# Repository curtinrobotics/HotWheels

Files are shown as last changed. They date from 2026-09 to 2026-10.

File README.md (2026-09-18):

# Hot_Wheels_RC

Welcome to the **Hot Wheels** project for Curtin Robotics club (CRoC)

This repository contains Arduino, ESP32, C++ codebases, hardware design, mechanical/electrical schematics.

---

## Project Structure

```text
Hot_Wheels_RC/
├── archive/                    -> archival assets, may be still relevant
├── docs/                       -> Documentation for the project
├── hardware_design/            -> CAD and schematic files for the hardware components
│   ├── Hot_Wheels_3d_model/    -> 3D model exported files (e.g., .stl, .step) for manufacturing and prototyping
├── Hot_Wheels_arduino_firmware/ -> Arduino firmware source code
```

## CAD - Onshape

This project uses Onshape for its CAD (computer-aided design) work. It is publicly available here: <https://cad.onshape.com/documents/5e98e5633ee093c54380ece6/w/86f2519afc7872e03f376baa/e/f928c5beb2e31589149b2275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>

## Collaboration Guidelines

To ensure smooth teamwork:

- **Commit, pull, and push frequently** to keep everyone on the same page.
- **Create a branch** for any experimental or testing-specific changes. Once stable, we can discuss merging them into the main codebase.
- If you have questions, feel free to reach out to Aron or Joshan

---

Contributors:

- **Shea, Aron**

---

## Nix Flake Quickstart (recommended)

This repo ships a `flake.nix` that pins the full Arduino toolchain (via Nix) and pins the _two ESP32 package indexes_ needed for this project:

- Espressif Arduino-ESP32 index
- Bluepad32 Arduino-ESP32 fork index

That means a new contributor can build on macOS/Linux without installing Arduino IDE, platform packages, or toolchains manually.

### Installing Nix

Nix is required to use this development environment. Install it using either the [official Nix installation guide](https://nixos.org/download/) or the [Determinate Nix Installer](https://manual.determinate.systems/installation/). The Determinate installer enables flakes by default.

### 1) Enter the dev shell

```sh
nix develop -c $SHELL
```

### 2) Confirm the ESP32 + Bluepad32 core is present

```sh
arduino-cli core list
```

You should see `esp32-bluepad32:esp32` installed.

### 3) Build the firmware

The target board for this project is **ESP32 Dev Module** from the Bluepad32 core:

- FQBN: `esp32-bluepad32:esp32:esp32`

#### Build with the flake

```sh
nix build
```

The generated firmware files are available under `./result/`. The `result` symlink is ignored by Git.

#### Build with the Nix-provided Arduino CLI

Run this from the development shell:

```sh
arduino-cli compile \
	--fqbn esp32-bluepad32:esp32:esp32 \
	Hot_Wheels_arduino_firmware/Hot_Wheels_arduino_firmware.ino
```

### 4) Flash and monitor the board

Enter the development shell if it is not already active, then identify the connected board:

```sh
arduino-cli board list
```

Set `PORT` to the port reported by the previous command. macOS ports commonly start with `/dev/cu.`, while Linux ports commonly start with `/dev/ttyUSB` or `/dev/ttyACM`.

#### Flash and monitor with the flake

```sh
PORT="<serial-port>"

nix run .#flash -- "$PORT"
nix run .#monitor -- "$PORT"
```

#### Flash and monitor with the Nix-provided Arduino CLI

Run this from the development shell. The commands use the firmware files generated by `nix build`:

```sh
arduino-cli upload \
	--input-dir result \
	--port "$PORT" \
	--fqbn esp32-bluepad32:esp32:esp32 \
	--verify

arduino-cli monitor \
	--port "$PORT" \
	--config baudrate=115200
```

If the board does not enter upload mode automatically, hold its **BOOT** button while starting the upload, then release it when the upload begins.

### Development checks

The flake provides repository-wide maintenance and checks:

```sh
# Fix and validate the repository
nix fmt
# or, from the development shell
fmt

# Check the repository
nix flake check
# or, from the development shell
chk

# Run an individual firmware check
nix run .#firmware-check
nix run .#flash -- "$PORT"
nix run .#monitor -- "$PORT"
```

The development shell also installs repository checks as pre-commit hooks.

### VS Code workflow

The repository includes editor settings and tasks in `.vscode/`. Extension choices are intentionally left to each contributor. In the command palette, use **Tasks → Run Task** to run the Nix build, formatter, flake check, board listing, flash, and serial monitor commands. The flash task builds the firmware first and then prompts for the board's serial port. If your editor does not automatically load `.envrc`, run `nix develop` manually.

### Notes on Bluepad32 library

The sketch includes `#include <Bluepad32.h>`. In this setup, the header is provided by the **esp32-bluepad32 platform package** (it bundles the library), so `arduino-cli lib list` may still show “No libraries installed” even though the include resolves.

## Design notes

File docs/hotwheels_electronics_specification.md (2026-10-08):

# Hot Wheels RC Electronics and PCB Specification

## Document control

| Field | Value |
| --- | --- |
| Status | Draft requirements capture |
| Target | 1:43-scale car, PCB Rev A  |
| Baseline controller | ESP32-WROOM-32UE-N8 |
| Last updated | 24 September 2026 |

## Purpose

This document records the intended features, design constraints and unresolved decisions for the car's electronics and PCB. It is the working reference for the schematic, PCB layout, firmware interfaces and later verification.

The document describes what the design needs to achieve. Component choices, dimensions and pin assignments can change as measurements and prototypes provide better information.

The terms below indicate how settled an item is:

- **Must** means it is required for the first board to be accepted.
- **Should** means it is strongly preferred unless a documented trade-off prevents it.
- **May** means it is optional or intended for a later revision.
- **TBD** means a decision or measurement is still required.

## Product intent

The vehicle is a 1:43-scale RC car intended to combine low-latency driving with telemetry and interactive track features. The PCB will contain the main electronics and form the structural centre of the chassis.

The design should remain modular. The body-mounted lights, forward distance sensor, floor colour sensor, wheel-speed sensor and motor thermistor should connect with cables so their positions can be adjusted and parts can be replaced. Front and rear mechanical sections should attach to the PCB and remain replaceable.

## Confirmed design direction

| Area | Decision |
| --- | --- |
| Vehicle scale | 1:43 |
| Main controller | ESP32-WROOM-32UE-N8 castellated module with 8 MB flash |
| Battery | 2S 600 mAh 20C LiPo, approximately 49 × 18 × 15 mm |
| Brushed motor driver | DRV8833 dual H-bridge |
| Motor-current sensing | Onboard sensing of both DRV8833 bridge currents |
| Battery-voltage sensing | Protected onboard divider connected to an ADC1 input |
| Inertial sensing | Onboard BMI160 three-axis accelerometer and three-axis gyroscope |
| Steering supply | Regulated 6 V |
| Steering connection | Three-pin connector; keyed preferred, with a controlled unkeyed DuPont exception |
| Forward ranging | Cable-mounted TOF400C module using VL53L1X |
| Floor colour sensing | Cable-mounted AS7341 V2 module |
| Motor temperature | Cable-mounted MF52B 10 kΩ, B3750 NTC thermistor |
| Initial wheel-speed sensor | Cable-mounted 49E Hall sensor and wheel magnet |
| Lighting | Dimmable underglow, headlights and taillights |
| Underglow | Top-mounted WS2812-family LEDs with a reflector or 3D-printed light redirector |
| Audio | Buzzer for interaction, warnings and find-me operation |
| Assembly | Reflowed parts on the top side only, suitable for hotplate assembly |
| Chassis | PCB forms the structural centre, with generic front and rear extensions |
| PCB envelope | 88 mm long, 44 mm maximum width and 12 mm front/rear arms |
| PCB thickness | 1.6 mm and 1.8 mm candidates; final choice after stiffness and cost comparison |
| Fasteners | M2 thin-head screws inserted from underneath |
| ESP32 mounting | Direct castellated-module footprint |
| Base-station radio | Direct peer-to-peer control and telemetry without joining the car's access point |

The ESP32-WROOM-32UE-N8 is the Rev A baseline. It replaces the earlier D1 Mini and ESP32-S module directions. The N8 variant provides 8 MB of flash for firmware and OTA update headroom, while the external-antenna variant uses an external antenna connection rather than relying on a selectable PCB-antenna/U.FL path.

## System overview

The 2S battery will feed the main input protection and power switch. Raw battery voltage will supply the DRV8833 and optional external ESC power connection. A dedicated regulator will produce 6 V for the steering servo. A dedicated 3.3 V logic supply will power the ESP32-WROOM-32UE-N8 and compatible sensors.

The ESP32 will handle motor and servo control, lighting, audio, sensor acquisition, Bluetooth controller support, ESP-NOW communication and telemetry. Motor-current, battery-voltage and inertial measurements will also support diagnostics, data logging and optional driver-assist functions.

The 6 V servo rail must not be connected directly to the ESP32 module's 3.3 V supply.

## Main functional requirements

- The PCB must operate as the electronic controller and structural centre of the 1:43-scale car.
- The car must provide proportional steering and proportional forward and reverse motor control.
- Propulsion must stop after communication loss, controller disconnection, ESP32 reset or a serious motor-driver fault.
- The body shell must be removable without desoldering lights or sensors.
- External sensors should be replaceable and positionable through keyed cable connections.
- The car must send live telemetry while being driven.
- Track-marker and power-up features must not make safe manual driving dependent on the central server.
- The board should provide accessible test points for power rails and critical signals.
- The PCB must measure battery voltage, motor current, acceleration and angular velocity.
- Driver assists must be independently configurable and must fail back to normal manual control when their inputs are invalid.

## Wireless control and telemetry

### Operating modes

| Mode | Control | Telemetry | Intended use |
| --- | --- | --- | --- |
| Base-station mode | Direct ESP-NOW or equivalent peer-to-peer link | Bidirectional over the same link | Primary Rev A mode |
| Direct-controller mode | Bluetooth Classic through Bluepad32 | Limited, stored locally or provided through a separately tested link | Standalone and fallback use |
| Development mode | External USB-C-to-UART programming adapter | Serial logging through the same adapter | Bench testing |

### Radio requirements

- The base station must not connect to the car's access point for control or telemetry, so the base station can retain its normal internet connection.
- ESP-NOW unicast between known peers is the first implementation choice for Rev A.
- The base station should pass telemetry to a computer over USB so the computer keeps its normal internet connection.
- The car must stop if valid control packets are not received within a defined timeout.
- Telemetry loss must not interrupt otherwise valid control.
- Packets must include a car identity, packet type, sequence number, command age and fault state.
- Each car must accept driving commands only from its paired base station during multi-car events.
- The radio channel must be documented and configurable.
- Bluetooth Classic and ESP-NOW share the ESP32 radio. Simultaneous operation must be measured before it is considered supported.

### Initial performance targets

| Measurement | Initial target |
| --- | ---: |
| Control update rate | At least 100 Hz |
| Typical command latency | 20 ms or less |
| Failsafe stop after lost control | 100 ms or less |
| Basic telemetry rate | At least 20 Hz |
| Packet-loss measurement | Continuous, using sequence numbers |

These values are starting targets for testing rather than fixed production limits.

## Battery and power

The selected battery is a 2S 600 mAh 20C LiPo measuring approximately 49 × 18 × 15 mm. Space must also be allowed for the cable, connector, bend radius and removal path.

A 2S LiPo is nominally 7.4 V and reaches 8.4 V when fully charged. All parts connected to the battery rail must tolerate the fully charged voltage.

### Planned power rails

| Rail | Source | Main loads |
| --- | --- | --- |
| VBAT | 2S LiPo | DRV8833 and optional ESC power pads |
| 6V_SERVO | 6 V MiniBuck module from VBAT | Steering servo |
| 3V3 | 3.3 V MiniBuck module from VBAT | ESP32-WROOM-32UE-N8 and compatible sensors |
| GND | Common return | All loads |

The current schematic uses separate fixed-output MiniBuck modules for the 6 V servo rail and 3.3 V logic rail. Any remaining 5 V loads must have an explicitly defined supply before schematic release; a 5 V rail is not assumed simply because some peripherals can use it.

### Power requirements

- The board must operate across the expected 2S battery range and tolerate 8.4 V at full charge.
- Battery polarity must be keyed and clearly marked.
- The battery connector must not mate with the motor or sensor connectors.
- The switch, protection, copper and connectors must be sized from measured system current.
- Battery voltage must be measurable through a protected divider connected to ADC1.
- Firmware must provide configurable low-battery warning and shutdown thresholds.
- Motor and servo current transients must not reset the ESP32 or corrupt sensor readings.
- Local ceramic and bulk decoupling must be provided at regulators, the motor driver, the servo connection and the ESP32 supply.
- The external USB-UART programming interface must not back-power the battery or 3.3 V rail through an unsafe path.
- Reverse-polarity, short-circuit and input transient protection must be reviewed before schematic release.
- The battery-voltage measurement circuit must tolerate at least 8.4 V plus component tolerances without exceeding the ESP32 ADC input range.
- Battery telemetry must distinguish sustained low voltage from short motor- or servo-induced voltage sag.

Rev A presently omits an inline fuse, MOSFET reverse-polarity protection and input TVS. This does not protect the PCB against reversed battery insertion or a hard short. Battery connector polarity must be checked before power-up; the supply path and wiring require review again after measuring motor and servo current. See the [schematic review](reva_schematic_review.md) for remaining acceptance gates.

The battery's 20C label implies an advertised current capability of 12 A. It does not mean the PCB needs to carry 12 A, but it means the battery may deliver destructive current into a fault. Actual motor and servo currents must be measured.

### Battery-voltage monitoring

The protected voltage divider will use an ADC1 input so it remains available while Wi-Fi is active. The input should include suitable filtering and protection, while the divider resistance must avoid unnecessary battery drain and remain compatible with the ADC input requirements.

Firmware will calibrate divider ratio and ADC error against a trusted meter. It should report raw and filtered battery voltage, detect rapid sag under load, and provide configurable warning, power-reduction and shutdown thresholds.

## Brushed motor system

The PCB will include a DRV8833 dual H-bridge.

It should support both:

- one brushed motor with the two bridges connected in parallel for additional current;
- two brushed motors using one independent bridge per motor.

The parallel and independent arrangements may use solder links, zero-ohm resistors or separate assembly variants. The selected arrangement must be obvious, and firmware must not drive the bridges independently while their outputs are tied together.

- Motor running and stall current must be measured before the driver package and copper layout are finalised.
- The DRV8833 must have hardware-defined safe input and nSLEEP states while the ESP32 is resetting.
- The nFAULT output should be routed to the ESP32 if a suitable pin is available.
- Motor connectors and wiring must be rated for measured stall current.
- Motor and battery connectors must be physically incompatible.
- Motor suppression and layout must limit brush noise and inductive transients.
- Each motor configuration must be tested separately for current, temperature, reversing and fault behaviour.
- The PCB must measure the current through both DRV8833 bridges.
- In dual-motor mode, bridge A and bridge B current must be available separately; in parallel-bridge mode, firmware must report their combined motor current.
- The current-measurement range must include normal running, acceleration and stall current with suitable transient margin.
- Current-sense failure or saturation must not be interpreted as a safe zero-current condition.
- Current warnings and software intervention thresholds must be configurable, but firmware must not replace the driver's hardware current regulation and thermal protection.

The current schematic uses the DRV8833PW package. Texas Instruments gives the PW package a lower continuous RMS rating than the thermally enhanced PWP and RTY versions. The final package choice therefore depends on measured current and thermal testing.

### Motor-current measurement

The DRV8833 AISEN and BISEN inputs support low-side sense resistors for bridge current regulation. Rev A should measure both sense paths so one circuit supports either two independent motors or one motor driven by parallel bridges.

The measurement circuitry must not load the sense nodes or change the hardware current-trip point. The schematic should provide Kelvin-connected sensing, appropriate gain and PWM-noise filtering, and test points for comparing the reported current with bench instruments. Current values must be calibrated and included in live telemetry, fault logging and stall detection.

## Optional brushless system

The PCB should retain the brushed driver while also providing an interface for a purchased external brushless ESC.

- The board should provide an external ESC signal and ground connection.
- The initial signal format is expected to be servo-style PWM, subject to the selected ESC.
- Any ESC-provided BEC output must be isolated by default.
- The ESC connection should be removable without affecting steering or sensors.

The interface may use labelled solder pads or a keyed connector, depending on available PCB area.

## Steering

The steering servo may use a 2.54 mm DuPont connector or another keyed three-pin connector. If an unkeyed DuPont connector is used, the pin order must place regulated 6 V on the centre pin, with signal and ground on the outer pins. This keeps the supply contact in the centre if the plug is reversed, but it does not eliminate signal/ground reversal risk. The unkeyed 2.54 mm DuPont connector is the only permitted unkeyed connector for Rev A.

- The 6 V regulator and connector must be sized for measured servo stall current.
- Steering direction, center trim, pulse range and endpoints must be configurable via software.
- Startup and communication-loss behaviour must not drive the linkage beyond its safe range.

## Sensors

### Sensor summary

In this table, “Onboard” means mounted directly on the PCB.

| Function | Device | Interface | Mounting |
| --- | --- | --- | --- |
| Wheel speed | 49E Hall sensor and wheel magnet | Analog | Adjustable cable-mounted sensor |
| Motor temperature | MF52B 10 kΩ, B3750 NTC | Resistive divider to ADC1 | Attached to the motor |
| Motor current | DRV8833 bridge sense resistors and measurement circuitry | Analog or dedicated current IC | Onboard |
| Forward distance | TOF400C with VL53L1X | I2C | Forward-facing cable-mounted module |
| Floor colour | AS7341 V2 | I2C (sensor + onboard LED control) | Downward-facing cable-mounted module |
| Battery voltage | Onboard divider | Analog | Onboard |
| Acceleration and angular velocity | BMI160 six-axis IMU | I2C or SPI, with data-ready interrupt preferred | Top side of the main PCB near its centre |

### Wheel speed

The 49E sensor will connect through a three-pin connector carrying 3.3 V, ground and signal. Its position must be adjustable relative to a magnet recessed into a wheel.

A 49E is a linear Hall sensor rather than a digital switch. The prototype can detect each magnet pass using an analog threshold. A digital Hall switch may replace it later if it gives cleaner pulse timing.

Wheel circumference and magnets per revolution must be configurable. One magnet is acceptable for the first prototype, although low-speed resolution and missed pulses need testing.

### Motor temperature

The MF52B 10 kΩ, B3750 thermistor will attach to the motor and connect through a two-pin cable. The PCB will contain the other resistor in the divider, and the measurement must use ADC1.

Firmware should support calibration, a warning threshold, reduced-power operation and a shutdown threshold. Open and shorted sensor faults should not be interpreted as valid temperatures.

### Forward ranging

The TOF400C/VL53L1X module will be positioned independently from the main PCB. Its connector should provide power, ground, SDA, SCL and, where exposed by the selected module, shutdown and interrupt.

The sensor may provide obstacle warnings, emergency intervention and distance-to-car information. It must not be treated as the only collision-safety mechanism.

Ranging must not block the steering and motor-control loop. Invalid or timed-out readings must not be interpreted as a clear path.

The VL53L1X field of view, timing budget, ambient-light performance and mounting angle need testing on the actual car. A fast short-range mode is likely more useful than its slow maximum-range setting.

### Floor colour and track markers

The AS7341 V2 module will face the track and connect through a cable. It will not be soldered to the underside of the main PCB.

The sensor needs controlled floor clearance and protection from striking the track. A small shroud should reduce interference from underglow, headlights, sunlight and body reflections.

Track markers will use unique three-colour sequences. They may identify track sections, report progress and request random power-ups from a central server.

Marker events should include:

- marker identity;
- local timestamp;
- detection confidence;
- duplicate suppression state.

Marker width, spacing, vehicle speed, illumination and sensor sample rate must be tested together so each colour bar produces enough readings.

### Inertial measurement and driver assists

The PCB will include a BMI160 containing a three-axis accelerometer and three-axis gyroscope. It should be mounted rigidly on the top side near the vehicle centre where practical, with its X and Y axes aligned to the vehicle axes. The sensor orientation and positive-axis directions must be marked on the silkscreen and recorded in firmware.

- The BMI160 supply must be locally decoupled and its placement must minimise interference from the motor driver, regulators, buzzer and high-current traces.
- A data-ready interrupt should be routed to the ESP32; the second interrupt should be routed if GPIO availability permits.
- The initial control-oriented sample-rate target is at least 200 Hz, subject to bus loading and measured noise.
- Firmware must calibrate accelerometer and gyroscope offsets and compensate for the documented PCB mounting orientation.
- Raw acceleration, angular velocity, calibration state and sensor-health information must be available to telemetry and logging.
- Invalid, stale or uncalibrated IMU data must disable dependent assists without interrupting manual steering or throttle control.

The first intended driver-assist experiment is bounded automatic counter-steer during a detected drift. It may use yaw rate, lateral acceleration, wheel speed, driver steering and throttle state. The assist must be disabled by default until calibrated, must limit its steering contribution, must allow immediate driver override and must never command steering beyond the tested mechanical endpoints.

### Shared I2C bus

The BMI160 now uses the existing 3.3 V I2C bus with address 0x68 (CSB tied high, SDO tied low), preserving its INT1 connection on GPIO16. This frees output-capable GPIOs for lighting and audio without adding an I/O expander. The VL53L1X, AS7341, ADS1115 and BMI160 share SDA/GPIO21 and SCL/GPIO22. Check actual breakout-board voltage tolerances, addresses, bus capacitance and onboard pull-ups before power-up; the main PCB has one 4.7 kΩ pair.

If their connectors are physically compatible, they must use the same safe power, ground, SDA and SCL ordering. Swapping two I2C modules should not damage either one.

The design should use one intentional set of bus pull-ups or configurable pull-ups. Pull-ups already fitted to the modules must be included in the calculation.

## Lighting and audio

### Lighting

| Function | Device | Interface | Mounting |
| --- | --- | --- | --- |
| Underglow  | WS2812B-2020-V6 (2 LEDs) | Digital (GPIO2, 3.3 V) | Top side of the main PCB |
| Headlights | White THT LEDs | Digital (transistor, PWM) | Removable body shell harness |
| Taillights | Red THT LEDs | Digital (transistor, PWM) | Removable body shell harness |

The underglow will use normal top-mounted WS2812-family LEDs. A reflective surface or simple 3D-printed light guide will redirect some light toward the ground. Uniform illumination is not required for Rev A.

The two 2020-size WS2812B-V6 pixels are powered directly from 3.3 V. The selected V6 variant must be purchased, not substituted with older 3.5 V-minimum versions. Worldsemi documents an integrated bypass capacitor on the 2020 version, so no separate per-pixel capacitors are placed. GPIO2 is a boot-strapping pin and the final assembly must verify that the data input does not force a high level during reset. The number and placement of pixels can be revised after optical and power-budget testing. See [Worldsemi WS2812B-2020-V6](https://www.world-semi.com/products/ws2812b-2020-v6.html).

The WS2812 power supply, data-line conditioning and bypass capacitors must follow the exact LED variant's requirements. If a 3.3 V ESP32 signal does not reliably meet the input-high requirement of LEDs powered from 5 V, a logic-level buffer should be included.

The body shell uses a keyed 5-pin JST ZH harness: 1 = +6 V, 2 = left headlight cathode, 3 = right headlight cathode, 4 = left taillight cathode, 5 = right taillight cathode. The LED anodes share +6 V. Each cathode returns through its own 470 Ω SMT resistor to one of two AO3400A low-side PWM switches (GPIO17 headlights, GPIO18 taillights). Each gate has a 100 kΩ pulldown to GND to hold the body lights off at reset. These resistors suit a provisional single white LED on each side of the front and a single red LED on each side of the rear; actual LED forward voltage, brightness and resistor power must be measured and the resistor values revised as necessary.

Lighting power and switching noise must not disturb the colour sensor, radio or ESP32 supply.

### Buzzer

Rev A uses a Same Sky (CUI Devices) CPT-9019S-SMT-TR passive 4 kHz SMD piezo, connected between GPIO19 and GND. Its specified current is 5 mA at 3 Vp-p, 4 kHz, so it is driven directly from the GPIO with no transistor. Validate the 3.3 V output waveform and pin loading during prototype bring-up. Sound playback must be nonblocking and must not interfere with motor failsafe handling.

## ESP32 and GPIO planning

Rev A uses the ESP32-WROOM-32UE-N8 directly on the PCB. The castellated module removes the D1 Mini carrier board, socket headers and onboard USB connector, reducing both footprint and stack height. The N8 variant is required so the design has 8 MB of flash for firmware growth and OTA update partitions.

The ESP32-WROOM-32UE-N8 uses an external antenna connector. The antenna, coax and connector require a protected mechanical route and clearance from the battery, motor, wiring, fasteners and noisy or grounded structures. The RF layout and antenna placement must follow Espressif's module guidance. An external antenna must be connected before the ESP32 is powered.

### Programming interface

USB-to-UART conversion remains off-board. Rev A should expose a compact programming/debug connector carrying the UART signals, ground and any required boot/reset control so a reusable external USB-C-to-UART adapter can program and log the car without dedicating PCB area and height to a USB connector and bridge IC.

The external programmer must not feed an unsafe voltage into the 3.3 V rail or back-power the battery path. Boot and enable circuitry must leave the module in a valid reset state when no programmer is attached.

### Rev A schematic GPIO allocation

| GPIO | Function | Notes |
| ---: | --- | --- |
| 0 | Programming BOOT | Keep boot/reset interface accessible |
| 1 / 3 | UART TX / RX | Off-board USB-UART programmer |
| 2 | WS2812B-2020-V6 data | Strapping pin: verify boot-time DIN loading |
| 4 / 5 | VL53L1X INT / XSHUT | Internal pull-up for interrupt; output-capable shutdown |
| 13 | DRV8833 nSLEEP | Hardware-defined safe startup state |
| 14 / 25 / 26 / 27 | DRV8833 bridge inputs | Four outputs support two bridges |
| 15 | Optional brushless ESC PWM | Strapping pin: verify ESC input at reset |
| 16 | BMI160 INT1 | Keep available for sensor event interrupt |
| 17 / 18 | Headlight / taillight PWM | Two AO3400A low-side driver gates |
| 19 | Passive piezo drive | Direct 3.3 V, current verified against piezo datasheet |
| 21 / 22 | I2C SDA / SCL | BMI160, ADS1115, VL53L1X, AS7341 |
| 23 | Spare | Unused output-capable GPIO |
| 32 | Analog Hall wheel-speed sensor | ADC1 |
| 33 | Steering servo PWM | 6 V servo supply is separate |
| 34 / 35 | Spare input-only | No internal pull-ups |
| 36 / 39 | Battery voltage / motor thermistor | ADC1 |
| 12 | Spare, strapping | Leave unconnected until reset-state constraints are checked |

The ADS1115 samples both motor-current sense channels without consuming ESP32 ADC pins. The battery divider, thermistor and Hall sensor remain on ADC1 so sensing can operate while Wi-Fi is active.

The BMI160 I2C allocation replaces an earlier SPI allocation. I2C timing and shared-bus behavior with the other sensors require firmware validation under combined operation. No I/O expander is included.

Boot-strapping pins must not be connected to circuits that force an invalid boot state. Sensor and lighting input states need checking during reset and programming.

## Connectors

Connectors should be easy to acquire and use, while preventing incorrect insertion, orientation or location that could cause over-voltage, reversed polarity or a short circuit.

### Connector rules

- Every removable connector must be keyed or mechanically unique, except for the steering servo, which may use the controlled unkeyed DuPont arrangement described above.
- Battery and motor connectors must never be mutually compatible.
- Incompatible voltages should use different families, pitches or pin counts.
- If two connectors can mate, their power and ground positions must be compatible.
- Pin one, voltage and function should be marked on the top silkscreen.
- Cable exits must avoid wheels, steering, gears, motor shafts and sharp PCB edges.
- High-current connectors must be selected using measured load current and wire size.

### Candidate connector plan

| Function | Pins | Candidate approach | Important constraint |
| --- | -----: | --- | --- |
| Battery | 2 | Match the pack (JST-PH) or use a dedicated keyed power family | Must be unique on the car |
| Brushed motor 1 | 2 | Different family from battery or direct solder pads | Stall current |
| Brushed motor 2 | 2 | Same safe motor pinout as motor 1 | Optional connection |
| Servo | 3 | Keyed 2.0 mm or locking connector; unkeyed 2.54 mm DuPont only under the documented pin-order rule | Servo stall current |
| VL53L1X | 4 to 6 | JST SH or equivalent | Include shutdown and interrupt if exposed |
| AS7341 | 4 to 6 | JST SH or equivalent | Confirm illumination and interrupt needs  |
| Hall sensor | 3 | Small keyed connector | 3.3 V, ground and signal |
| Thermistor | 2 | Small keyed connector unlike battery and motor | Passive sensor only |
| Body lighting | TBD | One keyed multi-pin connector | Body removal and current limiting |
| External ESC | 2 or 3 | Keyed signal connector or labelled pads | BEC isolated by default |

JST PH is rated for more current than JST SH and may suit some power connections. JST SH is smaller and may suit sensors. Final selection depends on measured current, component height, cable availability and assembly effort.

## PCB as chassis

The board will have a broad central electronics section with narrower front and rear structural extensions. Replaceable 3D-printed sections will attach to these extensions, allowing the mechanical layout or wheelbase to change without redesigning the electronics section.

### Coordinate system and Rev A outline

PCB coordinates use the board centre as the origin, positive Y toward the front and positive X toward the vehicle's right side. The Rev A outline is symmetric about both centre axes.

| Feature | Rev A value |
| --- | ---: |
| Model body length | 114 mm |
| Measured model wheelbase  | 64 mm |
| Front track | 40 mm |
| Maximum tyre envelope | 21.5 mm diameter × 8.7 mm width |
| PCB length | 88 mm, from Y = −44 to +44 mm |
| Maximum PCB width | 44 mm, from X = −22 to +22 mm |
| Centre rectangle | 44 mm wide × 44 mm long, from Y = −22 to +22 mm |
| Front and rear arm width  | 12 mm |
| Front and rear arm length | 22 mm, from Y = ±22 to ±44 mm |
| Candidate PCB thickness | 1.6 mm or 1.8 mm |

The Rev A outline is a simple square-ended shape. The 44 mm-wide centre rectangle ends at Y = ±22 mm, where it steps directly to the 12 mm-wide front and rear arms. The arm centreline remains X = 0, and the front and rear axle coordinates are Y = +32 mm and Y = −32 mm respectively.

The front and rear arms provide the structural interfaces for the replaceable 3D-printed sections. Fillets are not required for Rev A; a later mechanical revision may add them only if they preserve the hole pattern, component clearances and overall envelope.

### Mounting-hole pattern

All Rev A chassis holes are Ø2.3 mm non-plated holes for M2 fasteners. Hole coordinates denote centres.

| Group | X coordinates |  Y coordinates | Quantity |
| --- | ---: | ---: | ---: |
| Front arm | ±3 mm | +26 and +38 mm | 4 |
| Rear arm | ±3 mm | −26 and −38 mm | 4 |
| Main electronics area | ±19 mm | ±10 mm | 4 |

The pattern contains 12 holes in total. A nominal Ø4 mm fastener envelope is reserved around each hole. The main and arm holes retain 1.85 mm of PCB material from the drill edge to the nearest side edge, and the nominal fastener envelope leaves 1.0 mm of side clearance. The ESP32 module, antenna connector and coax route must remain clear of the mounting hardware. Thin-head screws enter from underneath. Standard M2 washers are unlikely to fit on the 12 mm-wide arms; actual screw heads, hex nuts and washers must be measured before the printed interfaces are finalised.

### Steering envelope

The initial steering target is 60° at the inner front wheel, with 65° used as the mechanical-clearance test. Using the 64 mm wheelbase, 40 mm front track, maximum tyre envelope and a provisional 0.5 mm inboard kingpin offset, the calculated tyre-to-arm clearances are approximately 2.27 mm at 60° and 2.13 mm at 65°. The result must be recalculated using the final kingpin and linkage geometry.

### External sensor mounting

The TOF400C/VL53L1X is nominally centred near Y = +51 mm on a vertical 3D-printed bracket attached to the front arm. The module and bracket must remain within the body envelope, avoid the steering mechanism and provide a clear forward field of view.

The AS7341 is nominally centred near Y = +8 mm on a separate downward-facing bracket beneath the chassis. It connects by cable to a top-side PCB connector and is not reflowed onto the underside. Its bracket must control floor clearance, protect the sensor from track strikes and provide an unobstructed optical opening.

- The outline must use a generic centre section with front and rear mounting extensions.
- Rev A must use simple square transitions into the narrower extensions; later fillets are optional and must preserve the defined envelope and hole pattern.
- Extension interfaces must use repeatable M2 hole patterns that can be referenced in CAD.
- M2 thin-head screws must enter from underneath to minimise lost ground clearance.
- Mounting holes should be non-plated unless an electrical connection is intentional.
- Nuts, inserts or printed bosses must support the board without crushing or flexing it.
- Rev A must use a 1.6 mm or 1.8 mm PCB after comparing stiffness, mass, availability and manufacturing cost.
- The outline must clear the battery, wheels, steering, drivetrain, body, wiring, sensors and USB cable.
- The internal shell width must clear the 44 mm PCB plus assembly and impact tolerance.
- The 12-hole pattern and coordinate origin must be shared with the 3D-printed part CAD.
- Steering clearance must be validated through the complete 65° inner-wheel test envelope before PCB release.

The exact choice between 1.6 mm and 1.8 mm remains open until a fabrication quote and chassis flex comparison are available. The selected value must then be used consistently by Onshape, KiCad and the manufacturing notes.

## Assembly constraints

- All reflowed components, connectors and PCB-mounted LEDs must be on the top side.
- The underside must remain component-free because it forms the lowest chassis surface.
- Through-hole leads and solder joints must not project into the ground-clearance envelope.
- The board must support one-pass hotplate assembly.
- Large modules and connectors need measured footprints, courtyards and height checks.
- The ESP32 antenna keep-out must be maintained even though the PCB is structural.
- The battery and cable-mounted modules must be removed before hotplate assembly or rework.

## Telemetry and event data

The initial telemetry format should be able to report:

- battery voltage and low-battery state;
- commanded and applied throttle and steering;
- wheel speed and estimated distance;
- bridge A, bridge B and combined motor current as applicable;
- motor temperature;
- three-axis acceleration, three-axis angular velocity and IMU calibration state;
- driver-assist enabled, active, requested correction and intervention-limit state;
- forward range and range-valid status;
- detected marker identity and confidence;
- radio signal or link-quality information;
- packet sequence, packet loss and command age;
- motor-driver, sensor, brownout and failsafe faults;
- lighting, buzzer and power-up state.

Track-marker events should include the car identity, marker identity, local timestamp, detection confidence and duplicate-suppression state.

The central server may assign power-ups, but the car must continue safe manual driving when the server or telemetry path is unavailable.

## Safety and failure behaviour

The design must define and test its response to:

- reversed battery connection;
- fully charged 2S input;
- low battery and sudden battery sag;
- motor stall or locked drivetrain;
- motor-current measurement saturation, disconnection or implausible readings;
- servo stall or steering jam;
- disconnected or shorted motor, servo, sensors and lights;
- ESP32 reset or firmware crash;
- Bluetooth loss and ESP-NOW packet loss;
- DRV8833 fault conditions;
- invalid or timed-out distance readings;
- invalid, stale or uncalibrated IMU readings while a driver assist is enabled;
- erroneous drift detection or counter-steer intervention;
- false, partial, duplicate and missed colour markers;
- the external USB-UART programmer and battery being connected together;
- a connector being inserted into the wrong socket;
- PCB flex, impact and loose fasteners.

Propulsion must fail safe to stopped. Lighting, audio, telemetry and sensor faults must not prevent the failsafe from operating.

## Verification

### Electrical bring-up

1. Inspect polarity, footprints, solder joints, connector orientation and configuration links, and confirm that the external antenna is connected before powering the ESP32.
2. Check resistance between all power rails and ground before power-up.
3. Power the board from a current-limited supply without the ESP32, servo, motor or sensors connected.
4. Verify every regulator across the expected battery range and representative load.
5. Verify USB and battery power-path behaviour before connecting both together.

### Functional testing

1. Verify safe motor states during power-up, reset, programming and firmware failure.
2. Test steering centre, endpoints, stall current and rapid direction changes.
3. Calibrate both motor-current channels against bench instruments and test running, acceleration, reversing and stall conditions.
4. Test each brushed configuration for current, reversing, fault handling and temperature.
5. Test the external ESC interface with its BEC isolated.
6. Check every connector against reverse insertion and plausible wrong-port insertion.
7. Operate lighting and the buzzer while monitoring ESP32 supply stability and radio packet loss.

### Sensor and radio testing

1. Calibrate Hall threshold, wheel circumference, missed pulses and speed accuracy.
2. Calibrate the thermistor and verify open and short fault detection.
3. Calibrate battery-voltage measurement across the expected battery range and characterise load-induced sag.
4. Calibrate BMI160 offsets, axis orientation, vibration sensitivity, sample timing and data-ready behaviour on the assembled car.
5. Validate counter-steer progressively with the wheels raised, then at low speed, while checking driver override and assist-disable behaviour.
6. Test VL53L1X behaviour with different targets, angles, sunlight and vibration.
7. Determine AS7341 illumination, floor clearance, sample rate and marker dimensions on the real track.
8. Measure ESP-NOW latency, jitter, packet loss, recovery and failsafe timing.
9. Test Bluetooth mode separately before attempting simultaneous Bluetooth and ESP-NOW operation.

### Mechanical testing

1. Fit-check the battery, body, motor, servo, wiring, programming cable and sensors.
2. Measure ground clearance below the screw heads.
3. Test PCB flex with the car supported at the front and rear mounts.
4. Inspect the narrow extension transitions and mounting holes after impacts.
5. Compare 1.6 mm and 1.8 mm PCB thicknesses before selecting the production stack-up.

## Remaining measurements and decisions

The design can continue without answering these immediately, but they are needed before the schematic and PCB are frozen:

1. ~Exact ESP32-WROOM-32UE-N8 supplier, footprint dimensions, antenna connector clearance and programming-header arrangement.~
2. Drive motor model, quantity, voltage, no-load current, loaded current and stall current.
3. Steering servo model, operating range, running current and stall current at 6 V.
4. Battery connector, wire gauge, cable exit and any built-in protection.
5. Body-shell internal width and height, programming-cable access, and fit of the printed front, rear and sensor brackets around the defined PCB envelope.
6. Default brushed configuration: one parallel-bridge motor or two independent motors.
7. Exact TOF400C and AS7341 boards, including voltage range, pinout and onboard pull-ups.
8. Confirm the planned two-pixel WS2812B-2020-V6 placement and adequacy of illumination.
9. Exact white/red body LED parts, luminous output, resistor power and the body-light harness fit.
10. Final choice between 1.6 mm and 1.8 mm PCB thickness, plus copper weight and manufacturing tolerances.
11. Motor-current measurement topology, amplifier or converter, full-scale range, shunt values and calibration method.
12. BMI160 shared-I2C timing/interrupt validation, final placement and any footprint-compatible procurement fallback.

## References

- [ESP32 Series datasheet](https://www.espressif.com/documentation/esp32_datasheet_en.pdf)
- [ESP32 ADC limitations](https://docs.espressif.com/projects/esp-idf/en/v4.2/esp32/api-reference/peripherals/adc.html)
- [Arduino-ESP32 ESP-NOW documentation](https://docs.espressif.com/projects/arduino-esp32/en/latest/api/espnow.html)
- [Espressif ESP-NOW examples](https://github.com/espressif/esp-now)
- [Bluepad32](https://github.com/ricardoquesada/bluepad32)
- [Texas Instruments DRV8833](https://www.ti.com/product/DRV8833)
- [Bosch Sensortec BMI160 datasheet](https://www.bosch-sensortec.com/media/boschsensortec/downloads/datasheets/bst-bmi160-ds000.pdf)
- [STMicroelectronics VL53L1X](https://www.st.com/en/imaging-and-photonics-solutions/vl53l1x.html)
- [Pololu VL53L1X Arduino library](https://github.com/pololu/vl53l1x-arduino)
- [ams OSRAM AS7341](https://ams-osram.com/products/sensor-solutions/ambient-light-color-spectral-proximity-sensors/ams-as7341-11-channel-spectral-color-sensor)
- [Adafruit AS7341 Arduino library](https://github.com/adafruit/Adafruit_AS7341)
- [JST PH connector specifications](https://www.jst-mfg.com/product/index.php?lang=2&series=199)
- [JST SH connector specifications](https://www.jst-mfg.com/product/index.php?series=231)

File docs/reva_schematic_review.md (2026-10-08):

# Rev A schematic review

The active design is in Hot_Wheels_Electronics/Hot_Wheels_Electronics.kicad_sch on the electronics branch. The original D1 Mini reference circuit is archived separately under archive/.

## Verification

| Check | Result |
| --- | --- |
| KiCad schematic ERC | 0 errors, 0 warnings |
| Active netlist export | Pass; verified test points, PWM sinks, I2C and supplies |
| BOM/footprint audit | 55 component line items, all assigned footprints; project MiniBuck library registered |
| Assembly footprint type | All active BOM footprints are SMD |
| Legacy D1 Mini archival | Complete; 168 active pin connections unchanged at extraction |
| Test points | TP1 +BATT; TP2 +6V; TP3 +3V3; TP4 GND; TP5 bridge-A current ADC; TP6 bridge-B current ADC |
| Functional circuits | Motor driver, dual current sensing, servo power, IMU, ToF, colour, wheel speed, battery/thermistor ADC, ESC, lighting and passive buzzer |

Recheck with these commands from the repository root:

    kicad-cli sch erc Hot_Wheels_Electronics/Hot_Wheels_Electronics.kicad_sch
    kicad-cli sch export netlist --format kicadxml -o /tmp/reva.xml Hot_Wheels_Electronics/Hot_Wheels_Electronics.kicad_sch
    kicad-cli sch export bom -o /tmp/reva-bom.csv Hot_Wheels_Electronics/Hot_Wheels_Electronics.kicad_sch

Zero ERC violations verify KiCad's electrical rules, not current ratings, thermal behavior, completed PCB layout or safe fabrication.

## Hardware implementation

- ESP32-WROOM-32UE-N8 with off-board USB-UART programmer and external antenna.
- BMI160 I2C address 0x68 (CSB high, SDO low), preserving INT1 on GPIO16. Shared 3.3 V SDA/GPIO21 and SCL/GPIO22 also serve ADS1115, TOF400C/VL53L1X and AS7341.
- DRV8833 two brushed bridges, independent 0.1 ohm low-side sense resistors and ADS1115 sensing. The driver reference is 200 mV, so the nominal hardware chopping threshold is around 2 A per bridge; this does not establish motor suitability.
- 6 V servo buck with local 22 uF and 100 nF capacitors.
- Two 3.3 V WS2812B-2020-V6 underglow pixels on GPIO2. White front and red rear body lamps use distinct PWM gates (GPIO17 and GPIO18), two AO3400A low-side switches, one resistor per LED return, and a 5-pin JST ZH harness.
- Direct GPIO19 drive of a 3 V-rated, 5 mA CPT-9019S-SMT-TR piezo.
- Two-wire off-board main switch attaches to small stock SMT solder pads. Motor outputs use keyed SMT Molex Micro-Fit connectors distinct from the JST-PH battery connector.

## Unresolved acceptance checks

1. **Power protection.** There is no inline fuse, reverse-polarity protection or TVS in Rev A. Confirm correct keyed LiPo polarity before applying power. A LiPo can source dangerous fault current; absence of the fuse is not a safety feature. Never power an unverified prototype unattended.
2. **Motor and servo current.** Measure running, startup, stall and reversal current under real mechanical load. Validate motor-driver thermal margin, two sense resistor power ratings, MiniBuck headroom, off-board switch/wiring, connector current rating, PCB copper dimensions and brownout behavior. Servo bulk capacitance is provisional.
3. **Current sensing.** Check shunt/Kelvin layout, ADS1115 signal range, PWM noise, calibration and failure handling with bench measurements before relying on software telemetry or stall detection.
4. **Boot safety.** Check ESP32 strapping pins GPIO2 (LED data) and GPIO15 (ESC), programmer/boot/reset operation, motor-driver control during reset and brownout, and safe firmware failsafe. DRV8833 nSLEEP has an internal 500 kilohm pull-down (TI datasheet); no additional resistor is placed.
5. **Breakout characteristics.** Confirm the purchased TOF400C/AS7341 supply voltage, logic voltage, I2C addresses, onboard I2C pull-ups and ToF interrupt/shutdown reset behavior; test combined I2C load and timing with BMI160.
6. **LED and buzzer operation.** Select actual white/red body LEDs and measure forward drop/output. Four 470 ohm series values are provisional. Confirm PWM, power/noise, underglow V6 supply and piezo current on assembled hardware.
7. **Mechanical/procurement.** Confirm board outline, one-sided reflow, Micro-Fit mating connector clearances, strain relief on SW1 wires, PCB antenna exclusion and external antenna routing. Confirm ESP32-WROOM-32UE-N8 and module-specific mounting details.
8. **Independent review.** Obtain the schematic/connector safety design-review sign-off and resolve the measurements above before fabrication.

## Status

**Electrical schematic assembled and ERC clean. Design-review approval and hardware-dependent checks remain open.** Issue #9 should remain open pending independent review and the required current/thermal/connector validation.

References: [TI DRV8833](https://www.ti.com/lit/ds/symlink/drv8833.pdf), [AO3400A](https://aosmd.com/res/data_sheets/AO3400A.pdf), [CUI CPT-9019S](https://www.digikey.com.au/htmldatasheets/production/1917703/0/0/1/cpt-9019s-smt-tr.pdf), [Worldsemi WS2812B-2020-V6](https://www.world-semi.com/products/ws2812b-2020-v6.html).

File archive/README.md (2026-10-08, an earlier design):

# Legacy hardware reference

`legacy_d1_mini.kicad_sch` preserves the original Wemos D1 Mini circuit and signal labels for reference. It is not part of the Rev A electrical design, BOM, or ERC scope.

The active Rev A schematic is `../Hot_Wheels_Electronics/Hot_Wheels_Electronics.kicad_sch` and uses the directly mounted ESP32-WROOM-32UE module.

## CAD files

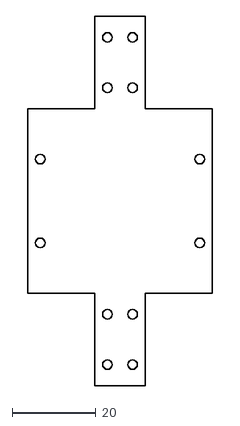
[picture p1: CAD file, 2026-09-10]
Hot_Wheels_Electronics/HotWheels_pcb_outline.dxf
44.0 x 88.0

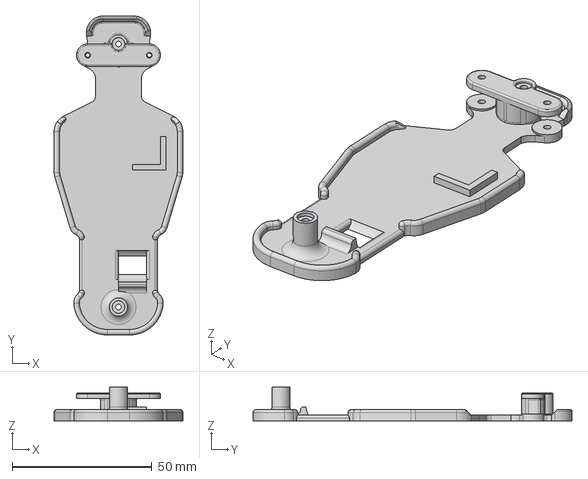
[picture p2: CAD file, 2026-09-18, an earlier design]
archive/hardware_design/Hot_Wheels_3d_model/Body.step
46.0 x 114.0 x 12.0 mm

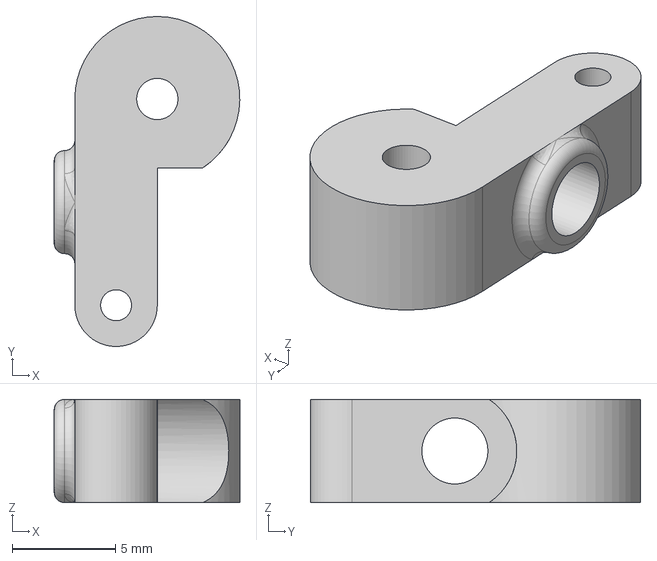
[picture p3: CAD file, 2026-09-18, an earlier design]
archive/hardware_design/Hot_Wheels_3d_model/SteeringKnuckle.step
9.00 x 16.0 x 5.00 mm

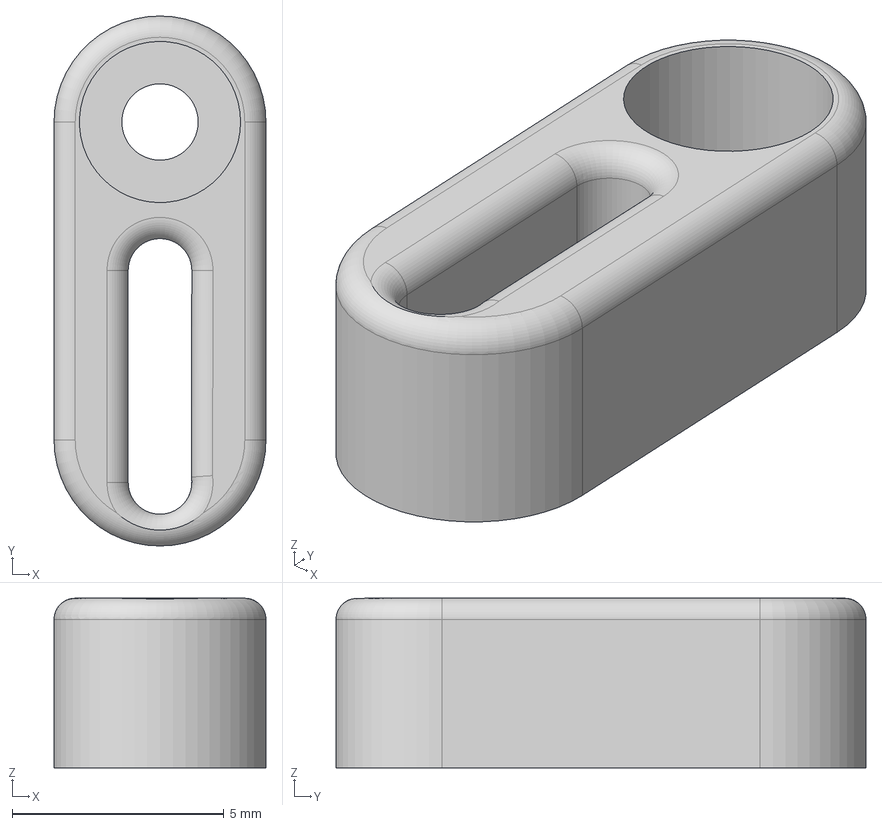
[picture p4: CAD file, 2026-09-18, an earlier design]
archive/hardware_design/Hot_Wheels_3d_model/ServoArm.step
5.00 x 12.5 x 4.00 mm

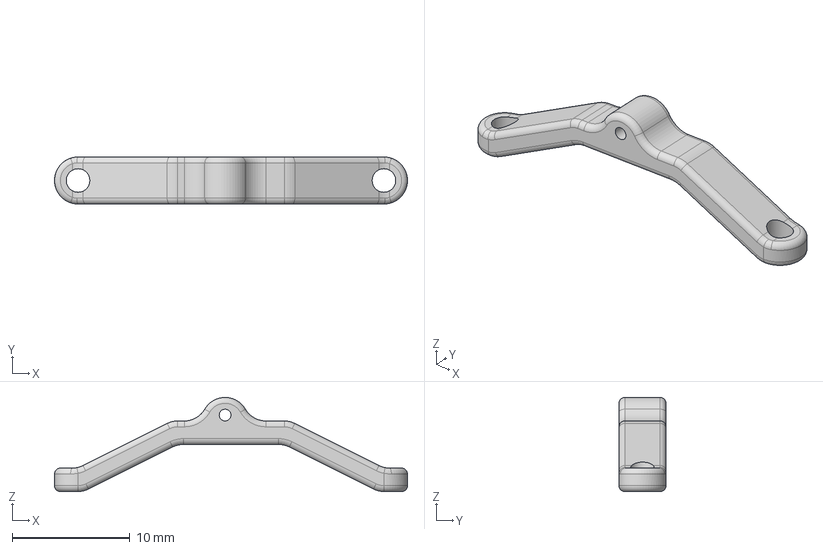
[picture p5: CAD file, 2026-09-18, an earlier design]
archive/hardware_design/Hot_Wheels_3d_model/TieRod.step
30.0 x 4.00 x 8.00 mm

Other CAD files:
archive/hardware_design/Hot_Wheels_3d_model.f3d

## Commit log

2026-09-03 Adrian’s PCB Schematic development (#33)
    * migrated to bare castellated module and used safe gpio pins
    * worked on programmer
    ---------
    [Hot_Wheels_Electronics.kicad_sch]
2026-09-10 initial commit for first draft of electronics
    [Hot_Wheels_Electronics.kicad_pcb, Hot_Wheels_Electronics.kicad_sch]
2026-09-10 added spi support to bmi160 imu
    [Hot_Wheels_Electronics.kicad_sch]
2026-09-10 added kicad .lck file to gitignore
2026-09-10 docs: add electronics specification and PCB outline
    [HotWheels_pcb_outline.dxf]
2026-09-10 chore: grouped schematic modules and increased page size
    [Hot_Wheels_Electronics.kicad_sch]
2026-09-10 feat: enabled two independent motor drivers
    [Hot_Wheels_Electronics.kicad_sch]
2026-09-17 finalised programming interface pinout
    [Hot_Wheels_Electronics.kicad_sch]
2026-09-17 correct gndio to gnd for bmi160
    [Hot_Wheels_Electronics.kicad_sch]
2026-09-17 placed do not place flag on old pcb mcu
    [Hot_Wheels_Electronics.kicad_sch]
2026-09-17 add the reset and boot schematic components
    [Hot_Wheels_Electronics.kicad_sch]
2026-09-17 added mini buck castellated module library
2026-09-17 added dedicated 3.3V and 6V buck modules
    [Hot_Wheels_Electronics.kicad_sch]
2026-09-18 Intialise and Introduce Onshape to the project (#35)
    * edited readme to add references to onshape
    * move old hardware designs to archive folder
    * fix typo in readme for onshape
    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
    [Body.step, Hot_Wheels_3d_model.f3d, ServoArm.step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]
2026-10-08 renamed to esp32-u
    [Hot_Wheels_Electronics.kicad_sch]
2026-10-08 fix: servo VIN to +6V
    [Hot_Wheels_Electronics.kicad_sch]
2026-10-08 updated electrical docs to follow current plan
2026-10-08 removed drv fault as it was deemed unnecessary
    [Hot_Wheels_Electronics.kicad_sch]
2026-10-08 worked on improving schematic compliance
    [Hot_Wheels_Electronics.kicad_sch]
2026-10-08 assigned correct footprints to all passives
    [Hot_Wheels_Electronics.kicad_sch]
2026-10-08 add no connect to drv8833 fault pin
    [Hot_Wheels_Electronics.kicad_sch]
2026-10-08 added no connects to bmi160
    [Hot_Wheels_Electronics.kicad_sch]
2026-10-08 assigned JST PH vertical SMT footprint to programming interface
    [Hot_Wheels_Electronics.kicad_sch]
2026-10-08 added a no connect flag and removed unused drv_nfault
    [Hot_Wheels_Electronics.kicad_sch]
2026-10-08 worked on schematic
    [Hot_Wheels_Electronics.kicad_sch]
2026-10-08 added battery voltage sense circuit
    [Hot_Wheels_Electronics.kicad_sch]
2026-10-08 add motor temperature sensing
    [Hot_Wheels_Electronics.kicad_sch]
2026-10-08 add wheel speed sensor interface
    [Hot_Wheels_Electronics.kicad_sch]
2026-10-08 add forward tof sensor interface
    [Hot_Wheels_Electronics.kicad_sch]
2026-10-08 add floor colour sensor interface
    [Hot_Wheels_Electronics.kicad_sch]
2026-10-08 assign compact but beefier footprint for power switch
    [Hot_Wheels_Electronics.kicad_sch]
2026-10-08 add external brushless esc interface
    [Hot_Wheels_Electronics.kicad_sch]
2026-10-08 register MiniBuck footprint library
2026-10-08 add ESP32 local supply decoupling
    [Hot_Wheels_Electronics.kicad_sch]
2026-10-08 separate motor connectors from battery family
    [Hot_Wheels_Electronics.kicad_sch]
2026-10-08 archive legacy D1 Mini schematic outside Rev A
    [Hot_Wheels_Electronics.kicad_sch, legacy_d1_mini.kicad_sch]
2026-10-08 model input power and DRV8833 VINT correctly
    [Hot_Wheels_Electronics.kicad_sch]
2026-10-08 add servo rail local decoupling
    [Hot_Wheels_Electronics.kicad_sch]
2026-10-08 add 3.3V WS2812 V6 underglow chain
    [Hot_Wheels_Electronics.kicad_sch]
2026-10-08 complete body lighting and audio interfaces
    [Hot_Wheels_Electronics.kicad_sch]
2026-10-08 add Rev A bring-up test pads
    [Hot_Wheels_Electronics.kicad_sch]
2026-10-08 document Rev A schematic verification and remaining risks
2026-10-08 docs: keep power safety note outside requirements list
2026-10-08 relocated identifier and label
    [Hot_Wheels_Electronics.kicad_sch]
2026-10-08 added four underglow LEDS
    [Hot_Wheels_Electronics.kicad_sch]
2026-10-08 cleaned up body lighting schematic zone
    [Hot_Wheels_Electronics.kicad_sch]
2026-10-08 cleaned up schematic
    [Hot_Wheels_Electronics.kicad_sch]
